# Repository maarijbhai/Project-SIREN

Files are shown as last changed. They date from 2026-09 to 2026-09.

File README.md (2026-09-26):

# SIREN: Sea Ice Remote Environmental Node

**A low-power sensing buoy that logs ice-floe motion in the Antarctic Marginal Ice Zone (MIZ).**
EEE4113F Engineering Design, University of Cape Town, March–June 2026 · Group 9: Maarij Alam, Ebrahim Bhyat, Josh Smith, Boitseko Senamela

This repository contains the **sensing subsystem** (Maarij Alam): STM32 firmware that samples a 6-DoF IMU and GPS, logs raw data to an SD card for post-processing on land, and hands position beacons to the comms subsystem. It also holds the acceptance-test firmware, analysis scripts and hardware design files.

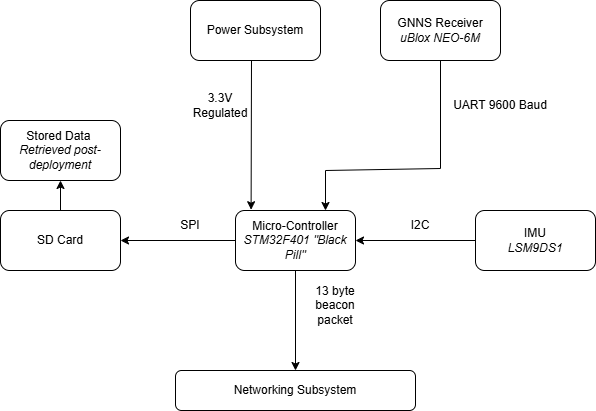
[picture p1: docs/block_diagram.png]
Block diagram


## Hardware
| Part | Interface | Pins (STM32F401CE "Black Pill") |
|---|---|---|
| LSM9DS1 IMU (accel + gyro) | I2C | SDA PB7, SCL PB6 (addr 0x6A) |
| u-blox NEO-6M GPS | UART2, 9600 baud | RX PA3, TX PA2 |
| MicroSD card (FAT32) | SPI | CS PB12 |
| ESP32 comms subsystem | UART1 | TX PA9, RX PA10 |

Firmware is C++ on the STM32duino core (Arduino IDE), flashed over SWD with an ST-Link V2. Schematics were drawn in KiCad.

## What the firmware does
[`firmware/SIREN_integrated/SIREN_integrated.ino`](firmware/SIREN_integrated/SIREN_integrated.ino)
- Samples the IMU at **~71 Hz** on a fixed timer, with a **high-pass filter** on vertical acceleration to remove gravity and drift (used for wave and collision detection).
- Parses GPS **NMEA $GPRMC** sentences **non-blockingly**, so a slow UART never stalls sampling.
- Buffers 500 rows in RAM and **flushes to `siren.csv` in blocks**, keeping SD writes off the sampling path.
- Answers `GET_DATA` requests from the ESP32 comms board with a position beacon (`ts,lat,lon` + `END_OF_DATA`).

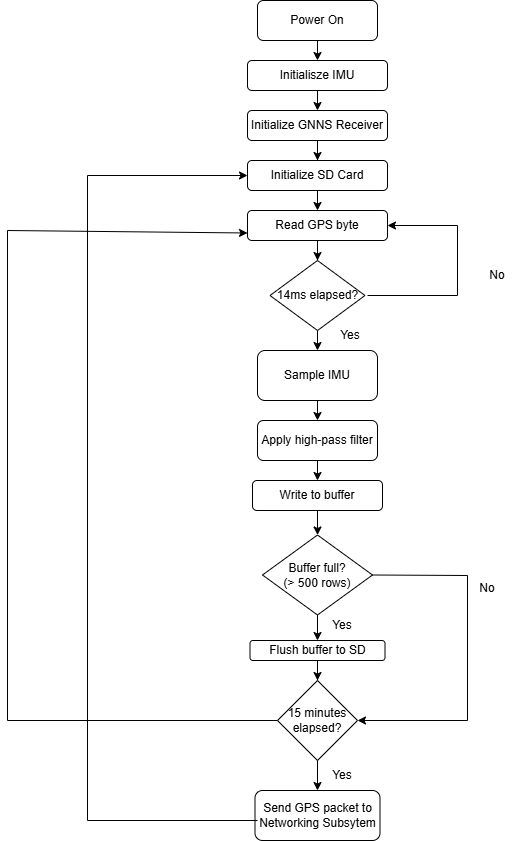
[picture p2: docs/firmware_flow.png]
Firmware flow


## Results
- **42,600 IMU samples** logged over a 10-minute run with **zero corrupted fields**.
- **71 Hz** achieved over I2C. The 100 Hz target was limited by I2C overhead; SPI was identified as the path to a higher rate.
- **65–75 mA** steady-state, ~100 mA peak, inside a **150 mA** power budget.
- Wave detection resolved the **1.05 Hz** test motion at **17.7 dB SNR**.
- GPS: **59.9 fixes/min**, 22.3 m accuracy under multipath.
- **7 of 9** acceptance tests passed.

## Acceptance tests
Every ATP has firmware (`.ino`) plus a Python script that validates the CSV it produces. See [`acceptance-tests/`](acceptance-tests).

| ATP | What it tests | Pass criteria |
|---|---|---|
| 1 | MCU boot | All peripherals initialise; 3.3 V rail 3.2–3.4 V |
| 2 | IMU static | Flat 9.81 ± 0.5 m/s², 45° 6.94 ± 0.5 m/s², filtered < 0.1 m/s² |
| 3 (tap) | Collision detection | Spike > 2 × RMS for ≥ 2 consecutive samples |
| 3 (shake) | Wave simulation | 1.0 ± 0.1 Hz peak, SNR ≥ 10 dB |
| 4 | GPS accuracy | Fix < 5 min, error < 10 m, 60 ± 3 sentences/min |
| 5 | SD integrity | Expected row count, zero nulls, no gaps > 15 ms |
| 6 | Current draw | IMU 4–6 mA, GPS 35–50 mA |
| 7 | Beacon packet | Matches GPS, correct interval and format |
| 8 | Endurance | Zero errors over a long run |

<!-- TODO (Maarij): add a "Result" column (PASS/FAIL + measured value) from the final report. -->

## Repository layout
```
firmware/
  SIREN_integrated/      full integrated firmware (IMU + GPS + SD + comms)
  bringup/               single-peripheral bring-up sketches (imutest, gps_test, sd_test, integration_t1)
acceptance-tests/atp_1…8 test firmware, captured CSVs, validate.py scripts, result plots
hardware/                KiCad schematic/PCB (sensing_board/), SPI variant schematic, pinouts
sims/                    signal simulation and spectrum of the expected wave motion
docs/                    block diagram and firmware flow
```

## Running the analysis
```bash
pip install numpy scipy pandas matplotlib
cd acceptance-tests/atp_5 && python validate.py      # e.g. SD integrity check on ATP5_DAT.CSV
```

---
Sensing subsystem by **Maarij Alam** · [maarijbhai.github.io](https://maarijbhai.github.io) · [project write-up](https://maarijbhai.github.io/projects/antarctic-remote-sensing/)

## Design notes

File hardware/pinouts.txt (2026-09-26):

LSM9DS1 IMU — I2C1
  SDA  → PB7  (labeled D15 / I2C1 SDA on pinout)
  SCL  → PB6  (labeled D10 / I2C1 SCL on pinout)
  VCC  → 3.3V
  GND  → GND
  SDO  → GND  (forces I2C address 0x6A)
  CS   → 3.3V (disables SPI mode, enables I2C)

NEO-6M GPS — UART2
  GPS TX → PA3  (Serial2 RX on pinout)
  GPS RX → PA2  (Serial2 TX on pinout)
  VCC    → 3.3V
  GND    → GND

SD Card — SPI1
  SCK  → PA5  (SPI1 SCLK on pinout)
  MISO → PA6  (SPI1 MISO on pinout)
  MOSI → PA7  (SPI1 MOSI on pinout)
  CS   → PB12 (SPI2 SSEL — used as GPIO CS)
  VCC  → 3.3V or 5V (check your module label)
  GND  → GND

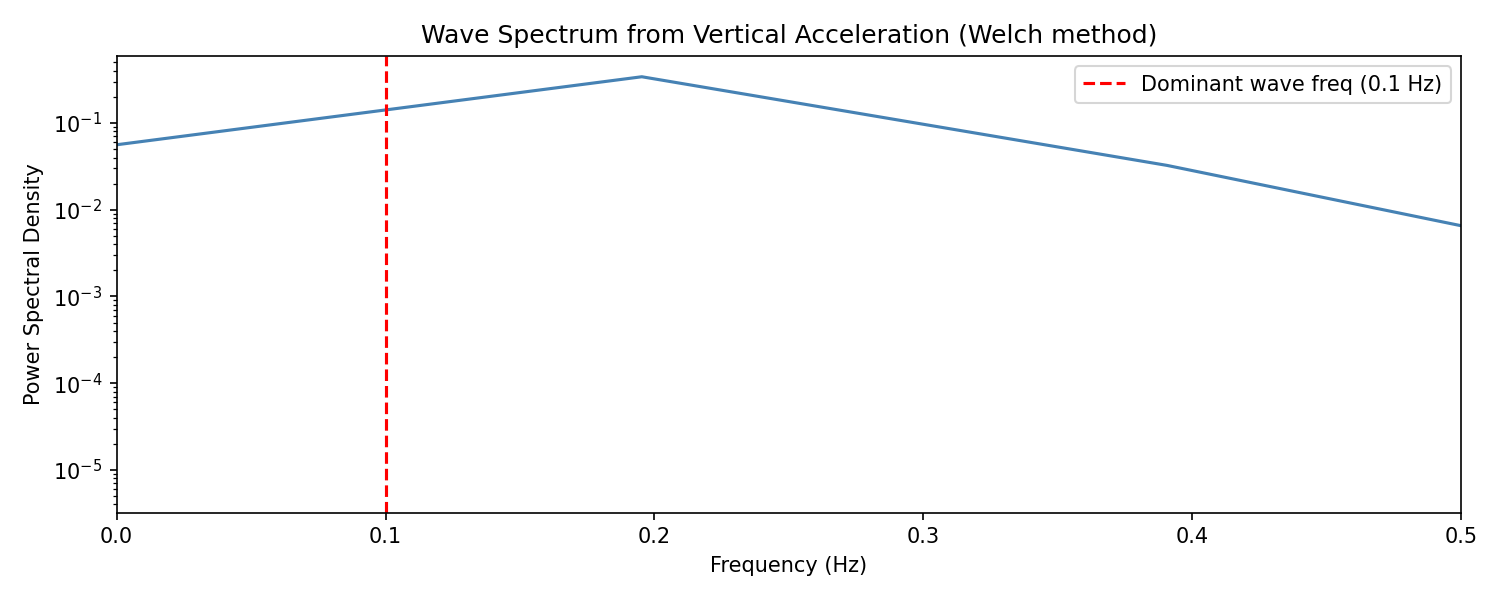
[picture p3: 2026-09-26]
sims/siren_spectrum.png

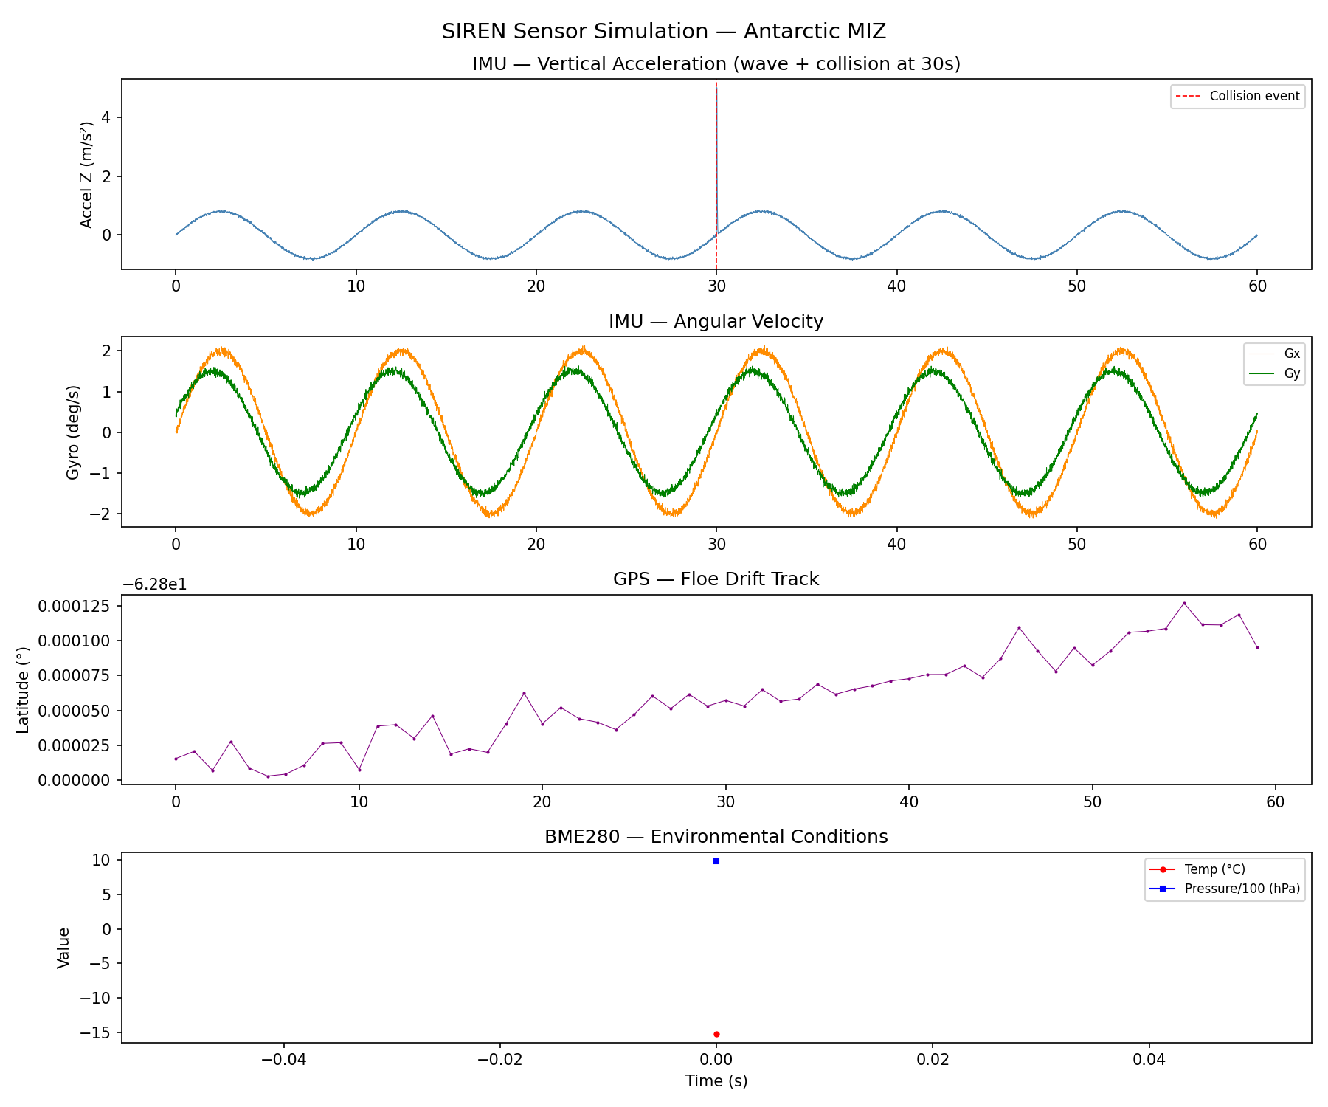
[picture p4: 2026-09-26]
sims/siren_simulation.png

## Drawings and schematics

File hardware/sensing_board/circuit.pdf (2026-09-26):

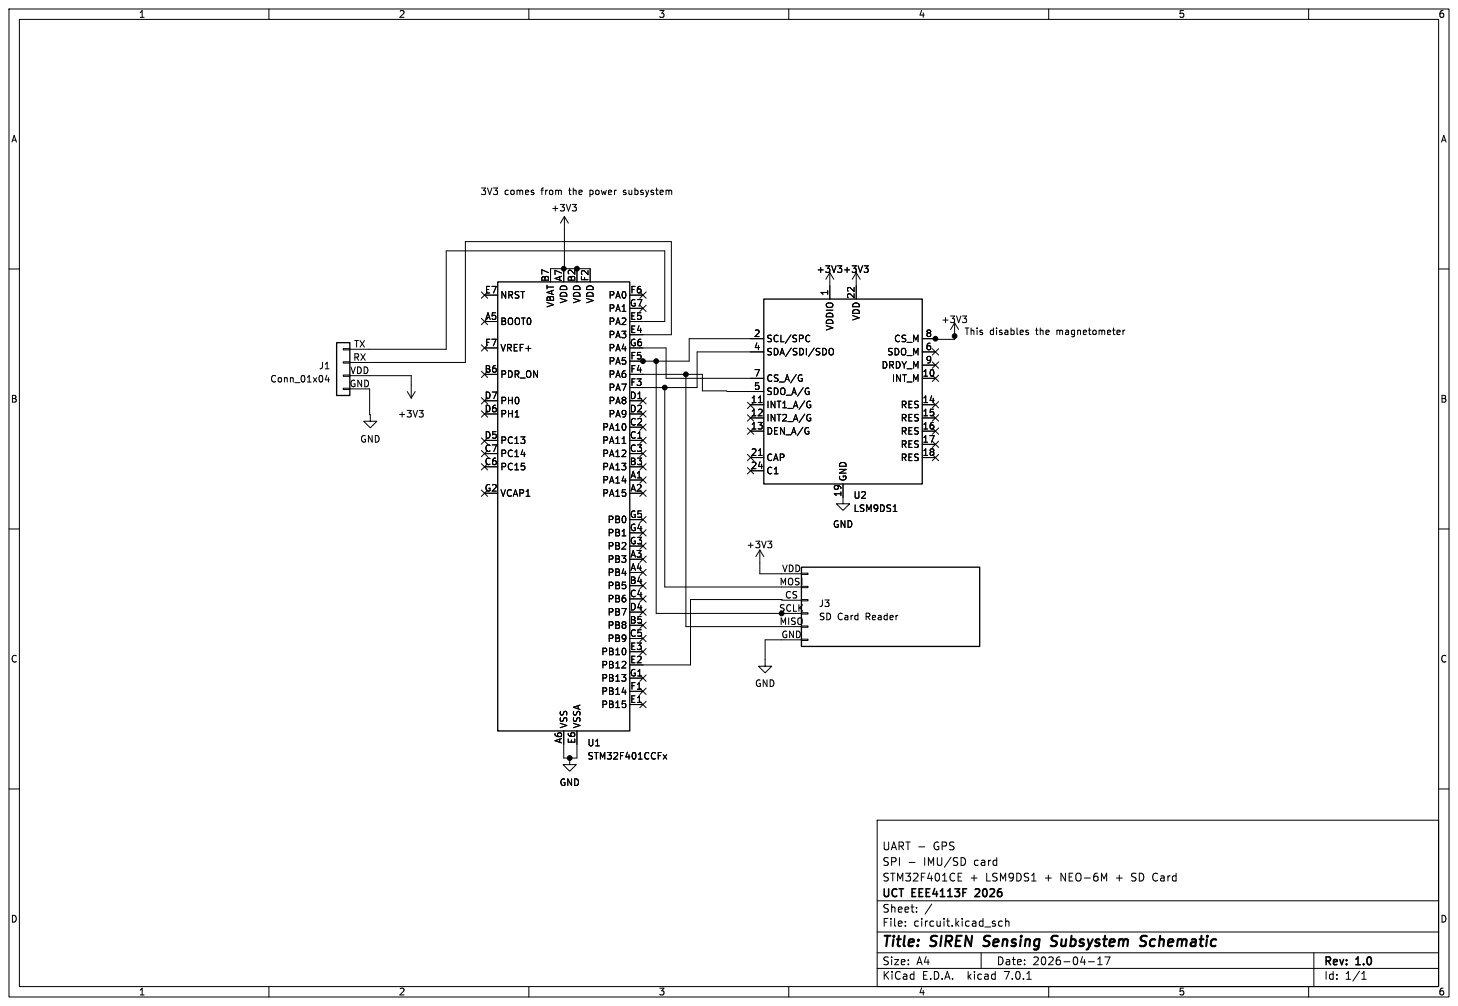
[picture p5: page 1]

VDD
CS GND MISO MOSI SCLK

Id: 1/1 Title: SIREN Sensing Subsystem Schematic

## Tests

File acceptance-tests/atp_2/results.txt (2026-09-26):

==============================
ATP-2: IMU Static Accuracy
==============================

PHASE 1: Place board FLAT on desk
Waiting 5 seconds to settle...
Recording 10 flat samples...
  Sample 10: az_raw = 9.681 m/s^2
  Sample 20: az_raw = 9.729 m/s^2
  Sample 30: az_raw = 9.712 m/s^2
  Sample 40: az_raw = 9.717 m/s^2
  Sample 50: az_raw = 9.734 m/s^2
  Sample 60: az_raw = 9.756 m/s^2
  Sample 70: az_raw = 9.705 m/s^2
  Sample 80: az_raw = 9.722 m/s^2
  Sample 90: az_raw = 9.741 m/s^2
  Sample 100: az_raw = 9.705 m/s^2

FLAT MEAN az_raw = 9.718 m/s^2
Expected:          9.810 +/- 0.500 m/s^2  [PASS]

PHASE 2: Tilt board to 45 degrees
Use phone inclinometer app
Hold steady then send any character in Serial Monitor
Recording 10 tilted samples...
  Sample 10: az_raw = 7.009 m/s^2
  Sample 20: az_raw = 7.123 m/s^2
  Sample 30: az_raw = 7.222 m/s^2
  Sample 40: az_raw = 7.415 m/s^2
  Sample 50: az_raw = 7.143 m/s^2
  Sample 60: az_raw = 7.049 m/s^2
  Sample 70: az_raw = 7.083 m/s^2
  Sample 80: az_raw = 6.901 m/s^2
  Sample 90: az_raw = 7.001 m/s^2
  Sample 100: az_raw = 7.056 m/s^2

45 DEG MEAN az_raw = 7.058 m/s^2
Expected:           6.940 +/- 0.500 m/s^2  [PASS]

PHASE 4: Place board FLAT again and hold still
Re-settling filter for 40 seconds...
Filter re-settled -- starting stationary check
PHASE 5: Hold board completely still for 30 seconds...

Max az_filt (stationary) = 0.0845 m/s^2
Required:                  < 0.100 m/s^2  [PASS]

==============================
ATP-2 COMPLETE
------------------------------
FLAT    [PASS]
45 DEG  [PASS]
FILTER  [PASS]
------------------------------
OVERALL [PASS]
==============================
Pull SD card and check atp2_dat.csv

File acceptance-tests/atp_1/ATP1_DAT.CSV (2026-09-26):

# ATP-1 Boot Test Results
peripheral | result | value
VDD_RAIL | PASS | 3.322V
IMU | PASS
SD_CARD | PASS
GPS_UART | PASS
OVERALL | PASS

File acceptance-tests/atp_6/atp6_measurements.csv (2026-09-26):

state | description | current_mA
0 | MCU only | 0
1 | MCU + IMU | 0
2 | MCU + IMU + GPS | 0
3 | Full system | 0

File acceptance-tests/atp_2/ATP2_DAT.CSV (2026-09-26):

# ATP-2 IMU Static Accuracy
phase | sample | az_raw | az_filt | timestamp_ms
FLAT | 1 | 9.7412 | 0.8446 | 8260
FLAT | 2 | 9.7220 | 0.8214 | 8290
FLAT | 3 | 9.7244 | 0.8196 | 8318
FLAT | 4 | 9.7364 | 0.8274 | 8348
FLAT | 5 | 9.7364 | 0.8233 | 8376
FLAT | 6 | 9.7292 | 0.8120 | 8406
FLAT | 7 | 9.6909 | 0.7699 | 8435
FLAT | 8 | 9.6981 | 0.7732 | 8465
FLAT | 9 | 9.7316 | 0.8026 | 8493
FLAT | 10 | 9.6814 | 0.7486 | 8523
FLAT | 11 | 9.6790 | 0.7425 | 8573
FLAT | 12 | 9.6909 | 0.7507 | 8603
FLAT | 13 | 9.6957 | 0.7517 | 8631
FLAT | 14 | 9.7149 | 0.7670 | 8661
FLAT | 15 | 9.6957 | 0.7441 | 8690
FLAT | 16 | 9.7149 | 0.7594 | 8720
FLAT | 17 | 9.7364 | 0.7771 | 8748
FLAT | 18 | 9.7173 | 0.7541 | 8782
FLAT | 19 | 9.7412 | 0.7742 | 8810
FLAT | 20 | 9.7292 | 0.7584 | 8838
FLAT | 21 | 9.6981 | 0.7237 | 8865
FLAT | 22 | 9.7077 | 0.7296 | 8894
FLAT | 23 | 9.7149 | 0.7331 | 8921
FLAT | 24 | 9.7340 | 0.7484 | 8949
FLAT | 25 | 9.7364 | 0.7471 | 8977
FLAT | 26 | 9.7244 | 0.7314 | 9005
FLAT | 27 | 9.6646 | 0.6683 | 9033
FLAT | 28 | 9.7244 | 0.7244 | 9061
FLAT | 29 | 9.7101 | 0.7065 | 9089
FLAT | 30 | 9.7125 | 0.7054 | 9117
FLAT | 31 | 9.7340 | 0.7233 | 9144
FLAT | 32 | 9.7244 | 0.7101 | 9172
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

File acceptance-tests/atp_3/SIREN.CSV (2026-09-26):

timestamp_ms | ax | ay | az_raw | az_filt | gx | gy | gz
10 | -0.2273 | -0.0359 | 9.4205 | 9.3734 | -0.0021 | 0.0269 | 0.0296
20 | -0.2369 | -0.0359 | 9.4229 | 9.3290 | 0.0365 | 0.0235 | 0.0301
30 | -0.2608 | -0.0191 | 9.4373 | 9.2966 | -0.0006 | 0.0247 | 0.0281
40 | -0.2608 | -0.0120 | 9.4899 | 9.3025 | -0.0082 | 0.0252 | 0.0289
50 | -0.2082 | -0.0072 | 9.5115 | 9.2774 | -0.0063 | 0.0325 | 0.0286
60 | -0.2417 | -0.0144 | 9.4062 | 9.1263 | -0.0027 | 0.0318 | 0.0267
70 | -0.2297 | -0.0191 | 9.5043 | 9.1782 | -0.0031 | 0.0255 | 0.0292
80 | -0.2297 | -0.0191 | 9.5067 | 9.1347 | -0.0020 | 0.0315 | 0.0281
90 | -0.2512 | -0.0526 | 9.5617 | 9.1438 | -0.0041 | 0.0270 | 0.0316
100 | -0.2034 | -0.0502 | 9.5043 | 9.0410 | -0.0008 | 0.0235 | 0.0325
110 | -0.2130 | -0.0359 | 9.4947 | 8.9862 | -0.0005 | 0.0228 | 0.0263
120 | -0.2512 | -0.0335 | 9.4971 | 8.9437 | -0.0040 | 0.0252 | 0.0299
130 | -0.2369 | -0.0144 | 9.5593 | 8.9609 | -0.0038 | 0.0263 | 0.0292
140 | -0.2130 | -0.0167 | 9.5115 | 8.8684 | -0.0024 | 0.0231 | 0.0255
150 | -0.2465 | -0.0383 | 9.4756 | 8.7884 | -0.0047 | 0.0279 | 0.0324
160 | -0.2345 | -0.0191 | 9.5019 | 8.7706 | -0.0014 | 0.0279 | 0.0284
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

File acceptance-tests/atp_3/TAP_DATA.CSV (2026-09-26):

# ATP-3 TAP TEST
timestamp_ms | ax | ay | az_raw | az_filt | gx | gy | gz
10 | -0.2871 | -0.0287 | 9.4469 | 9.3996 | -0.0026 | 0.0214 | 0.0264
20 | -0.2441 | -0.0191 | 9.4277 | 9.3336 | -0.0069 | 0.0279 | 0.0279
30 | -0.2249 | -0.0359 | 9.4636 | 9.3226 | -0.0020 | 0.0247 | 0.0249
40 | -0.2345 | -0.0239 | 9.4493 | 9.2617 | -0.0060 | 0.0246 | 0.0275
50 | -0.2441 | -0.0167 | 9.4708 | 9.2368 | -0.0040 | 0.0261 | 0.0272
60 | -0.2680 | -0.0167 | 9.5091 | 9.2288 | -0.0047 | 0.0281 | 0.0287
70 | -0.2369 | -0.0431 | 9.4780 | 9.1517 | -0.0050 | 0.0263 | 0.0279
80 | -0.2776 | -0.0167 | 9.4397 | 9.0678 | -0.0035 | 0.0273 | 0.0241
90 | -0.2273 | -0.0263 | 9.4995 | 9.0820 | -0.0049 | 0.0257 | 0.0281
100 | -0.2369 | -0.0335 | 9.5139 | 9.0509 | -0.0008 | 0.0304 | 0.0267
110 | -0.2608 | -0.0239 | 9.5186 | 9.0104 | -0.0012 | 0.0258 | 0.0261
120 | -0.1890 | -0.0383 | 9.5067 | 8.9534 | -0.0009 | 0.0254 | 0.0269
130 | -0.2632 | -0.0550 | 9.4995 | 8.9015 | -0.0027 | 0.0275 | 0.0295
140 | -0.2369 | -0.0191 | 9.4588 | 8.8165 | -0.0032 | 0.0266 | 0.0295
150 | -0.2489 | -0.0096 | 9.5234 | 8.8367 | -0.0053 | 0.0267 | 0.0254
160 | -0.2752 | -0.0335 | 9.4875 | 8.7568 | -0.0014 | 0.0287 | 0.0255
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

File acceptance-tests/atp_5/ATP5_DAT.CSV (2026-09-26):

# ATP-5 SD Integrity Test
timestamp_ms | ax | ay | az_raw | az_filt | gx | gy | gz
14 | -0.1316 | -0.0550 | 9.3751 | 9.3282 | 0.0044 | 0.0261 | 0.0415
28 | -0.1125 | -0.0407 | 9.4588 | 9.3649 | 0.0086 | 0.0223 | 0.0408
42 | -0.1292 | -0.0790 | 9.3942 | 9.2538 | 0.0108 | 0.0269 | 0.0417
56 | -0.0766 | -0.0670 | 9.4205 | 9.2337 | 0.0046 | 0.0264 | 0.0426
70 | -0.0957 | -0.1005 | 9.4373 | 9.2042 | 0.0061 | 0.0264 | 0.0406
84 | -0.1101 | -0.0407 | 9.4445 | 9.1653 | 0.0053 | 0.0250 | 0.0420
98 | -0.0502 | -0.0670 | 9.4373 | 9.1124 | 0.0089 | 0.0212 | 0.0432
112 | -0.0718 | -0.0981 | 9.4540 | 9.0835 | 0.0079 | 0.0235 | 0.0431
126 | -0.0766 | -0.0646 | 9.4708 | 9.0547 | 0.0064 | 0.0234 | 0.0429
140 | -0.1292 | -0.0790 | 9.4756 | 9.0142 | 0.0075 | 0.0235 | 0.0388
154 | -0.1053 | -0.0837 | 9.4421 | 8.9358 | 0.0099 | 0.0246 | 0.0403
168 | -0.1005 | -0.0646 | 9.4397 | 8.8887 | 0.0041 | 0.0270 | 0.0409
182 | -0.0861 | -0.0670 | 9.4732 | 8.8776 | 0.0058 | 0.0174 | 0.0429
196 | -0.1388 | -0.0694 | 9.5019 | 8.8618 | 0.0072 | 0.0209 | 0.0414
210 | -0.0814 | -0.1149 | 9.4540 | 8.7699 | 0.0079 | 0.0235 | 0.0425
224 | -0.1149 | -0.0622 | 9.4110 | 8.6832 | 0.0049 | 0.0240 | 0.0396
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

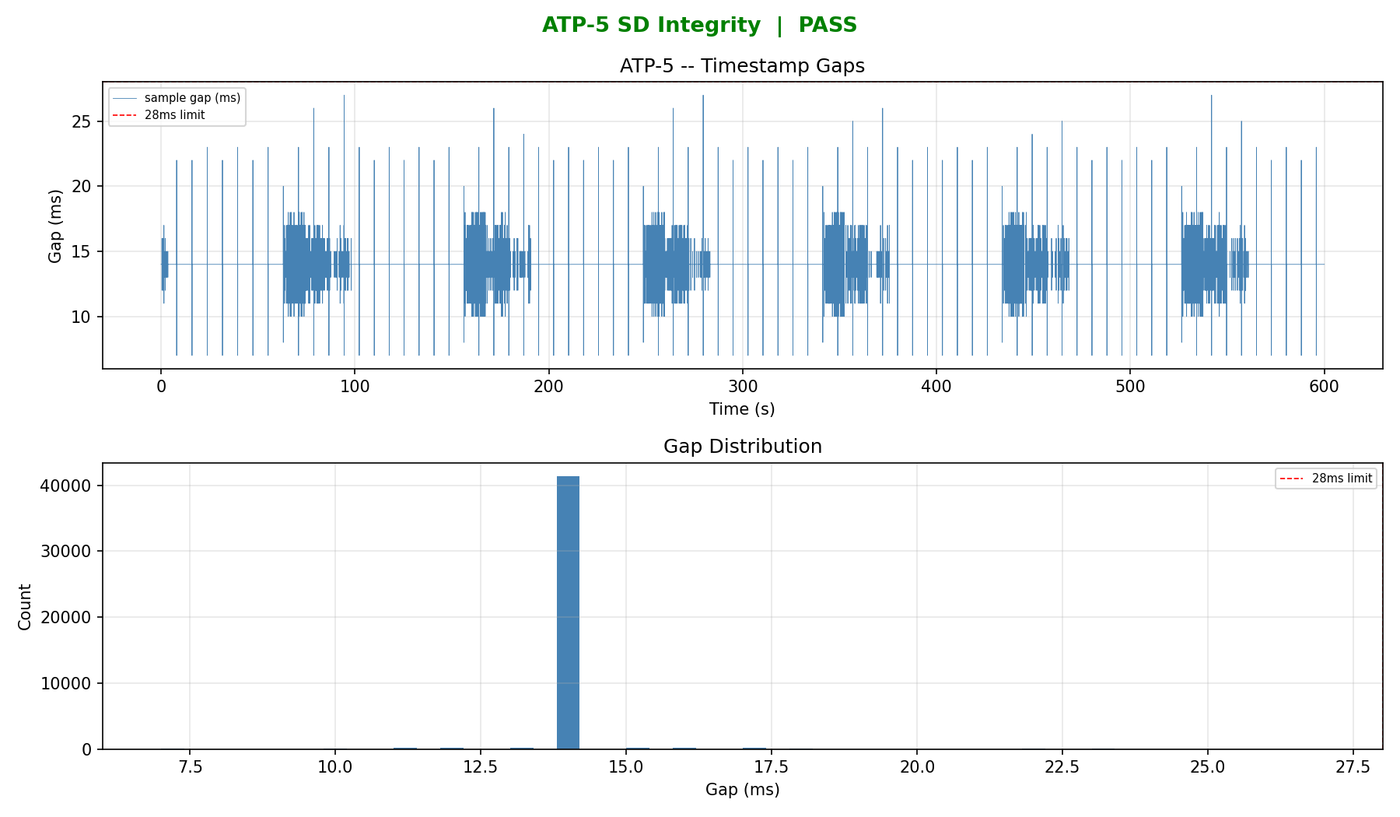
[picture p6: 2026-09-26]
acceptance-tests/atp_5/atp5_results.png

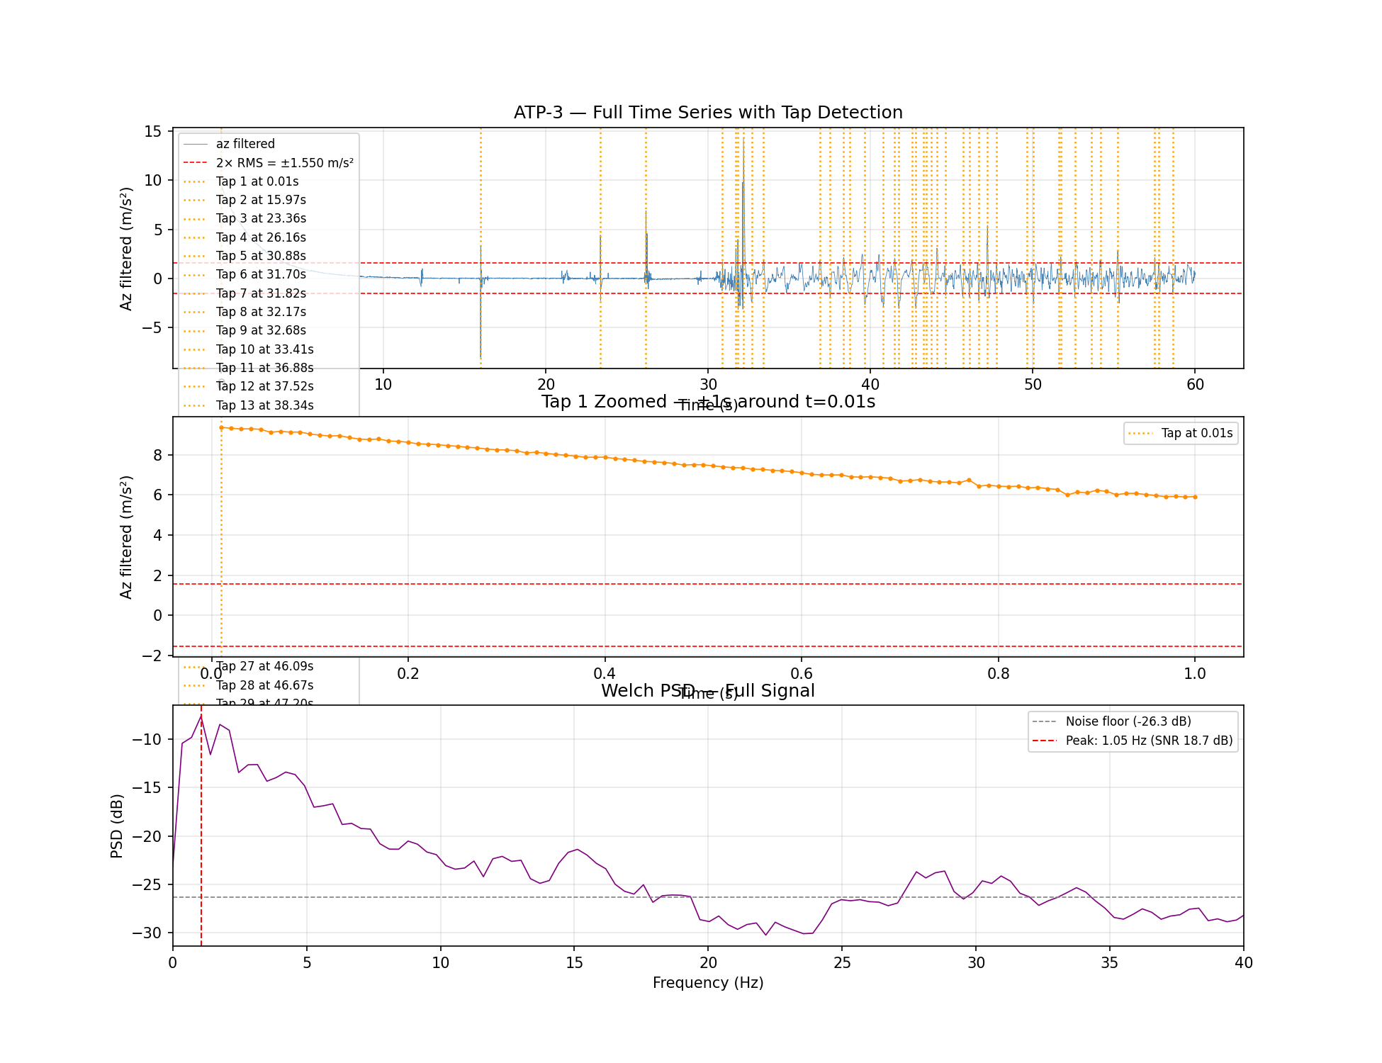
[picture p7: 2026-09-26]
acceptance-tests/atp_3/atp3_results.png

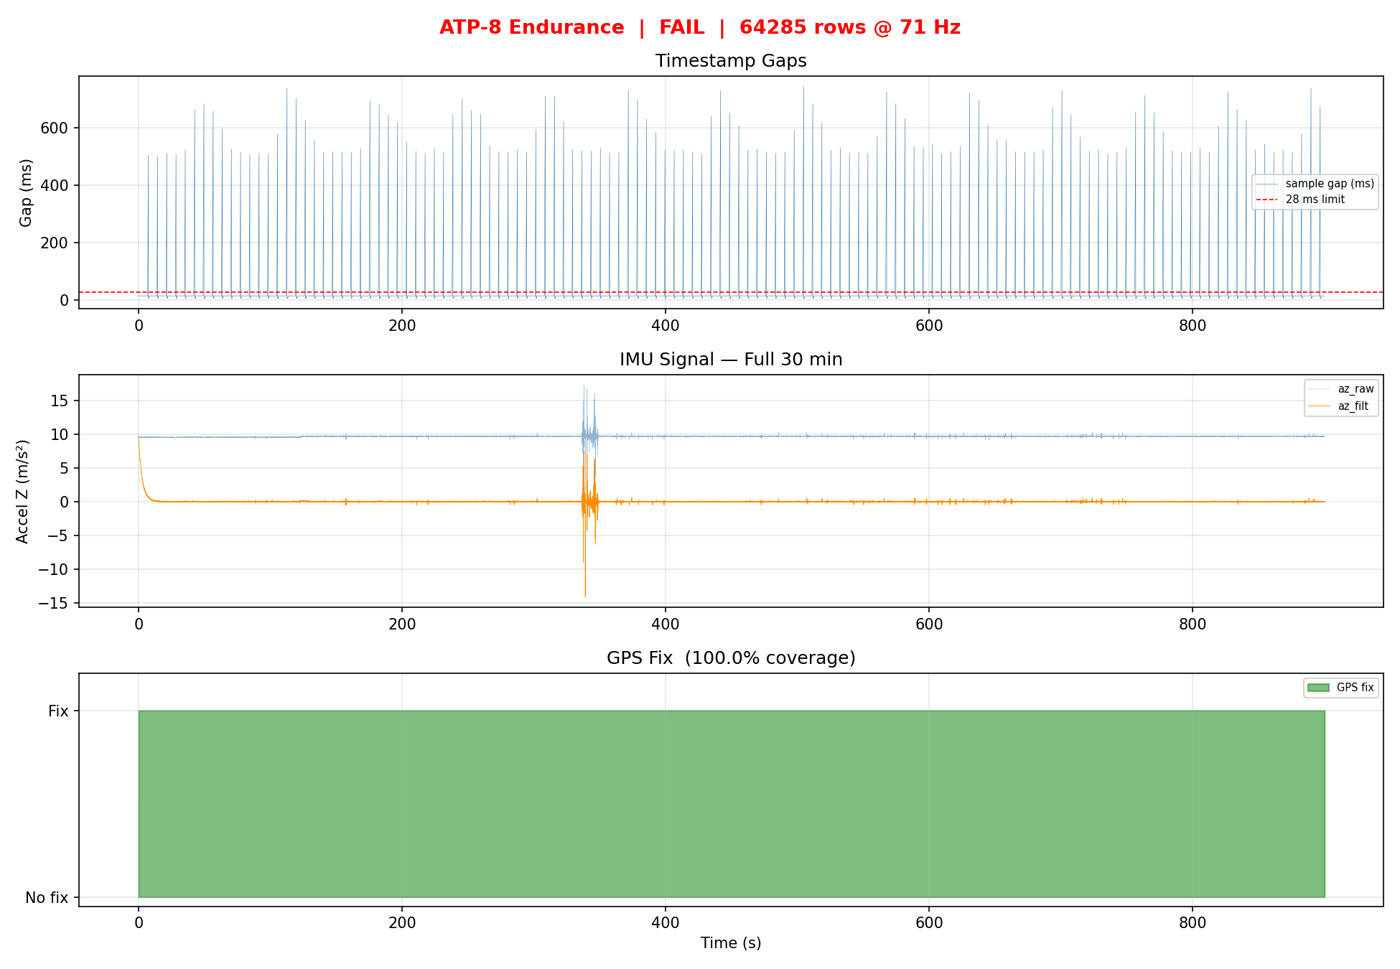
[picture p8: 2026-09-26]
acceptance-tests/atp_8/atp8_results.png

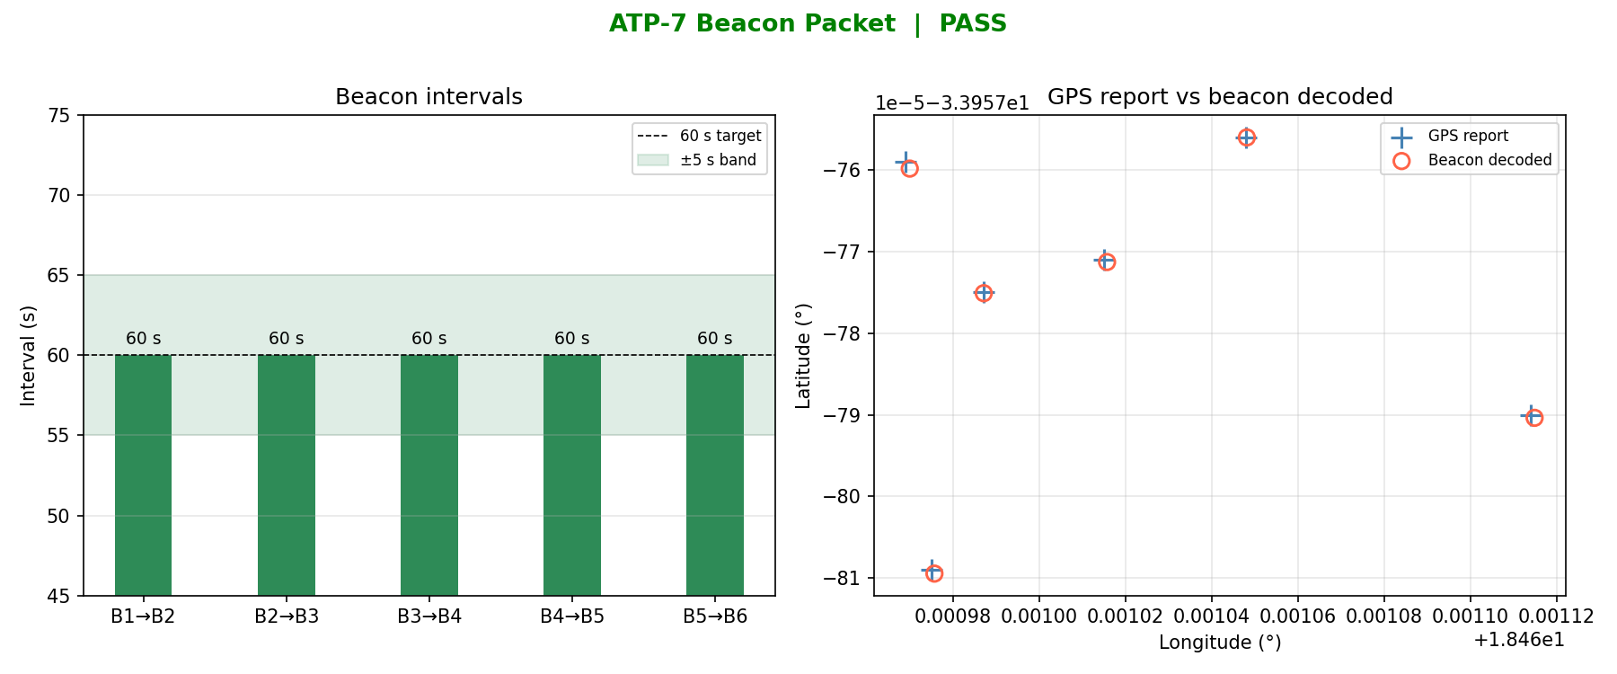
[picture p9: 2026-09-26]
acceptance-tests/atp_7/atp7_results.png

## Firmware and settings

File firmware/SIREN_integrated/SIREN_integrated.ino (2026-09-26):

// ============================================================
// SIREN — Full Integrated Firmware
// STM32F401CE Black Pill  |  EEE4113F Group 9  |  UCT 2026
//
// IMU:   LSM9DS1  I2C   SDA=PB7  SCL=PB6
// GPS:   NEO-6M   UART2 RX=PA3   TX=PA2  9600 baud
// SD:    Module   SPI   CS=PB12  MOSI=PA7 MISO=PA6 SCK=PA5
// COMMS: ESP32    UART1 TX=PA9   RX=PA10 9600 baud
//
// Beacon format every 15 min:
//   ts,lat,lon\n
//   END_OF_DATA\n
// ============================================================

#include <Wire.h>
#include <SPI.h>
#include <SD.h>
#include <Adafruit_LSM9DS1.h>
#include <Adafruit_Sensor.h>

// ── Pins ────────────────────────────────────────────────────
#define SD_CS_PIN       PB12

// ── Timing ──────────────────────────────────────────────────
#define SAMPLE_INTERVAL_MS  14UL        // ~71 Hz
#define BEACON_INTERVAL_MS  60000UL    // 15 min — use 60000 for testing
#define BUFFER_SIZE         500
char gps_utc[24] = "NO_FIX";

// ── Filter ──────────────────────────────────────────────────
#define HP_ALPHA  0.995f

// ── Peripherals ─────────────────────────────────────────────
Adafruit_LSM9DS1  imu;
HardwareSerial    GPS_Serial(PA3, PA2);   // RX, TX
HardwareSerial    Comms(PA10, PA9); 

// ── GPS state ───────────────────────────────────────────────
float   currentLat  = 0.0f;
float   currentLon  = 0.0f;
bool    gps_fix     = false;
String  nmeaBuffer  = "";

// ── IMU filter state ────────────────────────────────────────
float   az_prev     = 0.0f;
float   az_filt     = 0.0f;
bool    filter_init = false;

// ── Timing state ────────────────────────────────────────────
uint32_t lastSample = 0;
uint32_t lastBeacon = 0;
uint32_t rowCount   = 0;

// ── CSV row buffer ───────────────────────────────────────────
struct Row {
  uint32_t ts;
  float ax, ay, az_raw, az_filt;
  float gx, gy, gz;
  float lat, lon;
};
Row      buf[BUFFER_SIZE];
uint16_t bufHead = 0;

File dataFile;
bool sd_ok = false;

// ============================================================
// GPS — NMEA parser (GPRMC only, non-blocking)
// ============================================================
float parseCoord(String raw, String dir) {
  if (raw.length() < 4) return 0.0f;
  int dot = raw.indexOf('.');
  if (dot < 2) return 0.0f;
  float deg = raw.substring(0, dot - 2).toFloat();
  float min = raw.substring(dot - 2).toFloat();
  float result = deg + min / 60.0f;
  if (dir == "S" || dir == "W") result = -result;
  return result;
}

void parseGPRMC(String s) {
  // $GPRMC,hhmmss,A/V,lat,N/S,lon,E/W,...
  int idx[12];
  int n = 0;
  idx[n++] = 0;
  for (int i = 0; i < (int)s.length() && n < 12; i++) {
    if (s[i] == ',') idx[n++] = i + 1;
  }
  if (n < 7) return;
  String status = s.substring(idx[2], idx[3] - 1);
  if (status != "A") { gps_fix = false; return; }
  currentLat = parseCoord(s.substring(idx[3], idx[4]-1), s.substring(idx[4], idx[5]-1));
  currentLon = parseCoord(s.substring(idx[5], idx[6]-1), s.substring(idx[6], idx[7]-1));
  gps_fix = true;
}

void readGPS() {
  while (GPS_Serial.available()) {
    char c = GPS_Serial.read();
    if (c == '$') {
      nmeaBuffer = "$";
    } else if (c == '\n') {
      if (nmeaBuffer.startsWith("$GPRMC")) parseGPRMC(nmeaBuffer);
      nmeaBuffer = "";
    } else {
      nmeaBuffer += c;
      if (nmeaBuffer.length() > 100) nmeaBuffer = "";
    }
  }
}

// ============================================================
// SD — flush buffer to CSV
// ============================================================
void flushBuffer() {
  if (!sd_ok || bufHead == 0) return;
  for (uint16_t i = 0; i < bufHead; i++) {
    Row &r = buf[i];
    dataFile.print(r.ts);        dataFile.print(',');
    dataFile.print(r.ax,   4);   dataFile.print(',');
    dataFile.print(r.ay,   4);   dataFile.print(',');
    dataFile.print(r.az_raw,4);  dataFile.print(',');
    dataFile.print(r.az_filt,4); dataFile.print(',');
    dataFile.print(r.gx,   4);   dataFile.print(',');
    dataFile.print(r.gy,   4);   dataFile.print(',');
    dataFile.print(r.gz,   4);   dataFile.print(',');
    dataFile.print(r.lat,  6);   dataFile.print(',');
    dataFile.println(r.lon, 6);
    rowCount++;
  }
  dataFile.flush();
  bufHead = 0;
}

// ============================================================
// COMMS — send beacon to ESP32
// Format:
//   ts,lat,lon\n
//   END_OF_DATA\n
// ============================================================
void sendBeacon() {
  uint32_t ts = millis() / 1000;

  float lat = gps_fix ? currentLat : -33.95878f;
  float lon = gps_fix ? currentLon :  18.46029f;

  Comms.print(ts);
  Comms.print(',');
  Comms.print(lat, 6);
  Comms.print(',');
  Comms.print(lon, 6);
  Comms.print('\n');
  Comms.println("END_OF_DATA");

  Serial.print(F("[BEACON] ts="));
  Serial.print(ts);
  Serial.print(F(" lat="));
  Serial.print(lat, 6);
  Serial.print(F(" lon="));
  Serial.print(lon, 6);
  Serial.print(F(" fix="));
  Serial.println(gps_fix ? "YES — real GPS" : "NO — using fallback UCT coords");
}

// ============================================================
// SETUP
// ============================================================
void setup() {
  Serial.begin(115200);
  delay(3000);
  Serial.println(F("=== SIREN Boot ==="));

  // GPS
  GPS_Serial.begin(9600);
  Comms.begin(115200);

  // Comms to ESP32
  Comms.begin(115200);
  Serial.println(F("Comms UART OK"));

  // IMU — I2C
  Wire.setSDA(PB7);
  Wire.setSCL(PB6);
  Wire.begin();
  if (!imu.begin()) {
    Serial.println(F("FATAL: IMU not found"));
    while (1) {}
  }
  imu.setupAccel(imu.LSM9DS1_ACCELRANGE_8G,
                 imu.LSM9DS1_ACCELDATARATE_952HZ);
  imu.setupGyro(imu.LSM9DS1_GYROSCALE_245DPS);
  imu.setupMag(imu.LSM9DS1_MAGGAIN_4GAUSS);
  Serial.println(F("IMU init OK"));

  // SD — SPI
  SPI.setMOSI(PB15);
  SPI.setMISO(PB14);
  SPI.setSCLK(PB13);
  SPI.begin();
  pinMode(SD_CS_PIN, OUTPUT);
  digitalWrite(SD_CS_PIN, HIGH);
  delay(200);

  if (!SD.begin(SD_CS_PIN)) {
    Serial.println(F("FATAL: SD not found"));
    while (1) {}
  }
  dataFile = SD.open("siren.csv", FILE_WRITE);
  if (!dataFile) {
    Serial.println(F("FATAL: Cannot open siren.csv"));
    while (1) {}
  }
  if (dataFile.size() == 0) {
    dataFile.println(F("timestamp_ms,ax,ay,az_raw,az_filt,gx,gy,gz,lat,lon"));
  }
  sd_ok = true;
  Serial.println(F("SD init OK"));

  lastSample = millis();
  lastBeacon = millis();
  Serial.println(F("=== All systems OK — logging ==="));
}

// ============================================================
// LOOP
// ============================================================
void loop() {
  uint32_t now = millis();

  // GPS — non-blocking read
  readGPS();

  // Listen for GET_DATA from ESP32
  if (Comms.available()) {
    String cmd = Comms.readStringUntil('\n');
    cmd.trim();

    // Strip non-printable boot garbage
    String clean = "";
    for (int i = 0; i < cmd.length(); i++) {
      if (isPrintable(cmd[i])) clean += cmd[i];
    }

    Serial.print(F("[COMMS] RX: ")); Serial.println(clean);

    if (clean == "GET_DATA") {
      Serial.println(F("[COMMS] GET_DATA received — sending beacon"));
      flushBuffer();
      sendBeacon();
      Serial.println(F("[COMMS] Beacon sent"));
    }
  }

  // IMU sample at ~71Hz
  if (now - lastSample >= SAMPLE_INTERVAL_MS) {
    lastSample += SAMPLE_INTERVAL_MS;

    imu.read();
    sensors_event_t a, m, g, temp;
    imu.getEvent(&a, &m, &g, &temp);

    float ax = a.acceleration.x;
    float ay = a.acceleration.y;
    float az = a.acceleration.z;
    float gx = g.gyro.x;
    float gy = g.gyro.y;
    float gz = g.gyro.z;

    if (!filter_init) {
      az_prev     = az;
      az_filt     = 0.0f;
      filter_init = true;
    } else {
      az_filt = HP_ALPHA * (az_filt + az - az_prev);
      az_prev = az;
    }

    // Tap detection print for demo
    if (abs(az_filt) > 10.0f) {
      Serial.print(F("[TAP DETECTED] az_filt="));
      Serial.println(az_filt, 3);
    }

    buf[bufHead++] = { now, ax, ay, az, az_filt, gx, gy, gz, currentLat, currentLon };

    if (bufHead >= BUFFER_SIZE) flushBuffer();
  }

  // Periodic SD flush only — no auto beacon
  if (now - lastBeacon >= BEACON_INTERVAL_MS) {
    lastBeacon = now;
    flushBuffer();
    Serial.println(F("[SD] Periodic flush"));
  }
}

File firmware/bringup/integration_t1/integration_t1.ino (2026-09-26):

#include <Wire.h>
#include <SPI.h>
#include <SD.h>
#include <TinyGPS++.h>
#include <Adafruit_LSM9DS1.h>
#include <Adafruit_Sensor.h>

// ── Pin Definitions ──────────────────────────────────────────
#define SD_CS_PIN    PB12   // Your chosen CS pin
#define SPI_SCK      PA5
#define SPI_MISO     PA6
#define SPI_MOSI     PA7

// ── Serial ports ─────────────────────────────────────────────
HardwareSerial GpsSerial(PA3, PA2);  // RX=PA3, TX=PA2 (UART2)
TinyGPSPlus    gps;

// ── IMU (Adafruit instead of SparkFun) ───────────────────────
Adafruit_LSM9DS1 imu = Adafruit_LSM9DS1();

// ── Timing ───────────────────────────────────────────────────
#define IMU_INTERVAL_MS   10      // 100Hz
#define BEACON_INTERVAL_MS 900000 // 15 minutes

unsigned long lastIMU    = 0;
unsigned long lastBeacon = 0;

// ── GPS state ────────────────────────────────────────────────
float currentLat = 0.0;
float currentLon = 0.0;
bool  gpsFix     = false;

// ── High-pass filter state ───────────────────────────────────
float az_prev     = 0.0;
float az_filtered = 0.0;
float gx_prev     = 0.0;
float gx_filtered = 0.0;
float gy_prev     = 0.0;
float gy_filtered = 0.0;
const float alpha = 0.995;  // ~0.08Hz cutoff at 100Hz

// ── SD card file ─────────────────────────────────────────────
File dataFile;
bool sdReady = false;
int sdFlushCounter = 0; // Triggers the SD save every 100 samples

// ─────────────────────────────────────────────────────────────
// SETUP
// ─────────────────────────────────────────────────────────────
void setup() {
  Serial.begin(115200);
  
  // DFU SURVIVAL DELAY
  delay(3000);
  
  Serial.println("==============================");
  Serial.println("SIREN Sensing Subsystem v1.0");
  Serial.println("==============================");

  // Explicitly set I2C for IMU — PB7(SDA), PB6(SCL)
  Wire.setSDA(PB7);
  Wire.setSCL(PB6);
  Wire.begin();

  // Explicitly set GPS UART2 — PA3(RX), PA2(TX)
  GpsSerial.begin(9600);
  Serial.println("GPS UART2 started on PA2/PA3");

  // Explicitly set SPI1 for the SD Card
  SPI.setSCLK(SPI_SCK);
  SPI.setMISO(SPI_MISO);
  SPI.setMOSI(SPI_MOSI);
  SPI.begin();

  // IMU init
  if (!imu.begin()) {
    Serial.println("FATAL: IMU init failed. Check PB6/PB7 wiring.");
    while (1) { delay(100); }
  }
  
  // Setup IMU Ranges
  imu.setupAccel(imu.LSM9DS1_ACCELRANGE_4G);
  imu.setupGyro(imu.LSM9DS1_GYROSCALE_245DPS);
  Serial.println("IMU init OK");

  // SD card init
  if (!SD.begin(SD_CS_PIN)) {
    Serial.println("FATAL: SD init failed. Check SPI wiring.");
    while (1) { delay(100); }
  }

  // Open the file globally
  dataFile = SD.open("siren.csv", FILE_WRITE);
  if (dataFile) {
    if (dataFile.size() == 0) {
      dataFile.println("timestamp_ms,ax,ay,az_raw,az_filt,gx_raw,gx_filt,gy_raw,gy_filt,gz,lat,lon");
      dataFile.flush();
    }
    sdReady = true;
    Serial.println("SD init OK — File open and ready.");
  } else {
    Serial.println("FATAL: Could not open siren.csv");
    while (1) { delay(100); }
  }

  Serial.println("All systems GO. Logging started.");
}

// ─────────────────────────────────────────────────────────────
// MAIN LOOP
// ─────────────────────────────────────────────────────────────
void loop() {
  // Always feed GPS parser
  while (GpsSerial.available()) {
    if (gps.encode(GpsSerial.read())) {
      if (gps.location.isValid()) {
        currentLat = gps.location.lat();
        currentLon = gps.location.lng();
        if (!gpsFix) {
          Serial.println("GPS FIX ACQUIRED");
          gpsFix = true;
        }
      }
    }
  }

  // IMU at 100Hz
  unsigned long now = millis();
  if (now - lastIMU >= IMU_INTERVAL_MS) {
    lastIMU = now;
    
    imu.read();
    sensors_event_t a, m, g, temp;
    imu.getEvent(&a, &m, &g, &temp);

    float ax     = a.acceleration.x;
    float ay     = a.acceleration.y;
    float az_raw = a.acceleration.z;
    float gx_raw = g.gyro.x;
    float gy_raw = g.gyro.y;
    float gz     = g.gyro.z;

    // High-pass filter
    az_filtered = alpha * (az_filtered + az_raw - az_prev);
    az_prev     = az_raw;
    gx_filtered = alpha * (gx_filtered + gx_raw - gx_prev);
    gx_prev     = gx_raw;
    gy_filtered = alpha * (gy_filtered + gy_raw - gy_prev);
    gy_prev     = gy_raw;

    // Print to Serial (For PC Logger)
    Serial.print(now); Serial.print(",");
    Serial.print(ax, 4); Serial.print(",");
    Serial.print(ay, 4); Serial.print(",");
    Serial.print(az_raw, 4); Serial.print(",");
    Serial.print(az_filtered, 4); Serial.print(",");
    Serial.print(gx_raw, 4); Serial.print(",");
    Serial.print(gx_filtered, 4); Serial.print(",");
    Serial.print(gy_raw, 4); Serial.print(",");
    Serial.print(gy_filtered, 4); Serial.print(",");
    Serial.print(gz, 4); Serial.print(",");
    Serial.print(currentLat, 6); Serial.print(",");
    Serial.println(currentLon, 6);

    // Write to SD Card without closing it
    if (sdReady) {
      dataFile.print(now); dataFile.print(",");
      dataFile.print(ax, 4); dataFile.print(",");
      dataFile.print(ay, 4); dataFile.print(",");
      dataFile.print(az_raw, 4); dataFile.print(",");
      dataFile.print(az_filtered, 4); dataFile.print(",");
      dataFile.print(gx_raw, 4); dataFile.print(",");
      dataFile.print(gx_filtered, 4); dataFile.print(",");
      dataFile.print(gy_raw, 4); dataFile.print(",");
      dataFile.print(gy_filtered, 4); dataFile.print(",");
      dataFile.print(gz, 4); dataFile.print(",");
      dataFile.print(currentLat, 6); dataFile.print(",");
      dataFile.println(currentLon, 6);
      
      // Flush to physical memory every 100 samples (1 second)
      sdFlushCounter++;
      if (sdFlushCounter >= 100) {
        dataFile.flush();
        sdFlushCounter = 0;
      }
    }
  }

  // Beacon every 15 minutes
  if (millis() - lastBeacon >= BEACON_INTERVAL_MS) {
    lastBeacon = millis();
    Serial.println("=== BEACON ===");
    Serial.print("LAT: ");    Serial.println(currentLat, 6);
    Serial.print("LON: ");    Serial.println(currentLon, 6);
    Serial.print("BAT%: ");   Serial.println(100);
    Serial.print("TIME_MS: "); Serial.println(millis());
    Serial.println("==============");
  }
}

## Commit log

2026-05-18 3D print designs
    [Body1.3mf, Body4.3mf, EB.f3d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]
2026-05-18 Revert "3D print designs"
    This reverts commit 25db805422186ebb774f1e3decc4df45cdfeb617.
    [Body1.3mf, Body4.3mf, EB.f3d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]
2026-09-26 Add sensing subsystem: integrated firmware, ATPs, hardware and README
    Moves the work from the Sensing branch onto main in a clean layout,
    adds the previously unpushed integrated firmware, and drops course
    admin files (minutes, slides, readings, backups).
    [ATP1_DAT.CSV, ATP2_DAT.CSV, ATP5_DAT.CSV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]
